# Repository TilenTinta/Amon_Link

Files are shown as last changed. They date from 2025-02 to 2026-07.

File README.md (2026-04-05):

# Amon Link

USB-powered RF bridge between **Amon Ground Control** (PC) and the **Amon Lander** drone, built around the WCH **CH32V003F4P6** MCU with **dual NRF24L01 + RFX2401C** radios for robust range. 

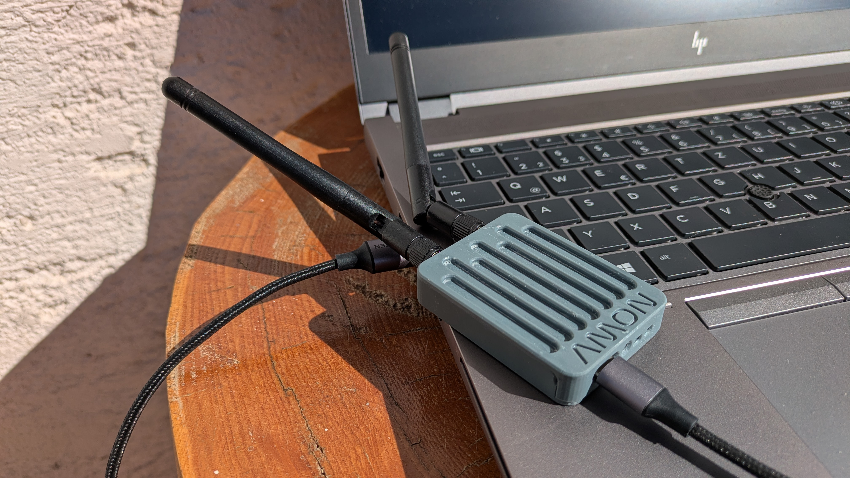
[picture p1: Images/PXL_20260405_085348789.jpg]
Amon Link
  

> Part of the Amon Lander project:
>
> - **Amon Lander** — overall vehicle, frame, test/control SW, and data  
>   https://github.com/TilenTinta/Amon_Lander
> - **Amon Board** — flight controller hardware & firmware  
>   https://github.com/TilenTinta/Amon_Board
> - **Amon Ground Control** — desktop GCS for telemetry & control  
>   https://github.com/TilenTinta/Amon_GroundControl_Software

---

## Table of Contents

- [Overview](#overview)
- [Features](#features)
  - [Hardware](#hardware)
  - [Software & Compatibility](#software--compatibility)
  - [Diagnostics & Controls](#diagnostics--controls)
- [Quick Start](#quick-start)
- [Flashing Firmware](#flashing-firmware)
- [Debugging](#debugging)
  - [LED Status Codes](#led-status-codes)
  - [Button Usage](#button-usage)
- [Repository Structure](#repository-structure)
- [Roadmap](#roadmap)
- [Status & Disclaimer](#status--disclaimer)
- [License](#license)
- [Acknowledgments](#acknowledgments)

---

## Overview

**Amon Link** is a compact, low-power **RF communication bridge** that connects a PC-based Ground Control application to the Amon Lander over 2.4 GHz radios. It prioritizes reliability by pairing **two NRF24L01 modules** with the **RFX2401C PA/LNA** front-end for extended range and improved link quality. The board is powered from **USB Type‑C** and integrates a **3.3 V LDO**. 

---

## Features

### Hardware

- **MCU:** WCH **CH32V003F4P6**. 
- **Power:** USB‑powered with onboard **3.3 V LDO**. 
- **Connector:** **USB Type‑C**. 
- **RF Link:** Dual **NRF24L01** radios with **RFX2401C (PA+LNA)** for long range and better SNR. 
- **Indicators/Controls:** Status LED and button for reconnect/SW update. 

### Software & Compatibility

- **Firmware:** C, developed in **MounRiver Studio IDE**. 
- **USB–UART:** **CH340G** bridge (install drivers if needed). 
- **Platforms:** Works with **Windows, Linux, and macOS** Ground Control apps. 
- **Updates:** **Custom bootloader** supports USB firmware updates. 

### Diagnostics & Controls

- **Status LED** for connection state. 
- **Button** to trigger manual reconnect and entering bootloader mode. 

---

## Quick Start

1. **Connect** the Amon Link board to your PC using **USB‑C**.   
2. **Install drivers** if required for **CH340G**.   
3. **Place antennas** for the two NRF24L01 radios to ensure clear line‑of‑sight where possible.   
4. **Launch** the Amon Ground Control application and select the appropriate COM port.

---

## Flashing Firmware

- Open the project in **MounRiver Studio IDE**, compile, and **upload** to the **CH32V003F4P6** MCU. 

> The board also includes a **custom bootloader** for **USB firmware updates** which is supported by the desktop software. 

### Bootloader
Firmware for device also includes bootloader option. To flash that:
- First flash bootloader (folder: **Bootloader**),
- after that you can flash main **hex** file over USB and desktop app (folder: **Firmware**)

If bootloader is not used you **MUST** modify the code in folder **Firmware**. In file `Link.ld` change code on the top of the file to:

```c
/* Full flash 16KB */
__app_size = 16K;

MEMORY
{
  /* Application region - 16KB */  
	FLASH (rx) : ORIGIN = 0x00000000, LENGTH = __app_size 

  /* RAM - untouched 2KB */  
	RAM (xrw)  : ORIGIN = 0x20000000, LENGTH = 2K
}

SECTIONS
{
  .init :
  {
    ...
```
Once the bootloader is flashed, you can put your device in firmware update mode by holding the **Reconnect** button while plugging in the USB cable or by triggering it via software. When the blue and red LEDs are lights up, you're in firmware update mode!

The firmware can be updated using a graphical application. The application is built with a Python backend and an Electron front end. You can select and import either a hex or a binary file. Once imported, the CRC32 checksum is calculated for the file.

This checksum is used during device connection. When the device connects, a handshake process exchanges several pieces of data, one of which is the CRC32 value of the firmware currently installed on the device. If this CRC matches the one from the new file, you are notified before proceeding with the update. After a successful update, the new CRC32 value is written to the device for future reference.

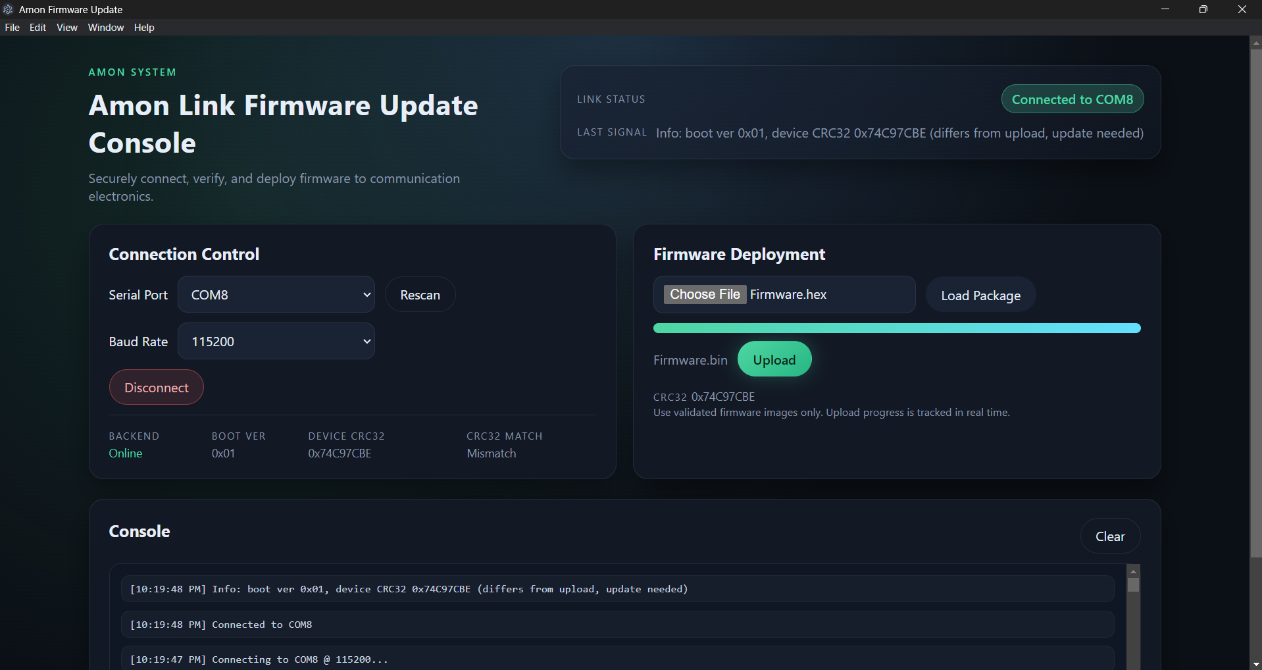
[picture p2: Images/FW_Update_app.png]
Amon Link fw app
  

---

## Debugging

### LED Status Codes  

| LED Pattern (App) | Meaning |
|---|---|
| Constant blinking **red** | Device initialization failed |
| Solid **blue** | Device initialized |
| Blinking **red** | Received packet |

| LED Pattern (Boot) | Meaning |
|---|---|
| Solid **blue** and **red** | Waiting on USB data |

### Button Usage  

Press the **button** to trigger a manual **reconnect** attempt or befor powring up device to enter bootloader mode.

## Range testing
The plan for this device is not to reach over 1 km of range, but only a few meters are enough for now. To test this, I did a simple test. I connected the device to my laptop and established a connection from the **Ground control app** to **Amon Link** and from that to **Amon Lander**. After receiving telemetry data, I started moving away from the drone. This test was done with line of sight between the drone and link device.

Range test  

Because of field limitations, the test was not done until telemetry cut-off. The test will be repeated in the future to really get the limitation of radio range.

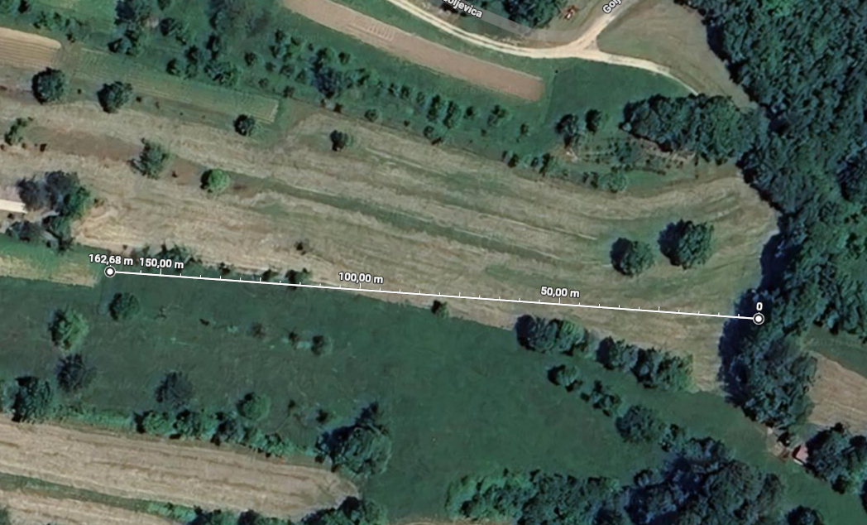
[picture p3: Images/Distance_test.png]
Range test
  

---

## Status & Disclaimer

**In active development.** The hardware and firmware are usable, but changes are ongoing; expect rough edges as features evolve.

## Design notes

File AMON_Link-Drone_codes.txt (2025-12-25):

++++++++++++ Drone state machine ++++++++++++

#define STATUS_STARTUP		0
#define STATUS_IDLE_NC		1 // not connected
#define STATUS_IDLE_CN		2 // connected
#define STATUS_ERROR		3
#define STATUS_ARM			4
#define STATUS_FLY			5
#define STATUS_FLY_OVER		6

#define RF_STATUS_CN		1
#define RF_STATUS_NC		0

++++++++++++ Link state machine ++++++++++++

#define NO_RADIO            1           // Number of radios (1 or 2)

#define CONN_STATUS_OK      1           // Flag that indicates the connection status - connected
#define CONN_STATUS_NOK     0           // Flag that indicates the connection status - disconnected

#define STATE_INIT          0           // State machine value: boot-up (blue light)
#define STATE_CONN_START    1           // State machine value: try to connect (reconnect triggers the same state)
#define STATE_CONN_OK       2           // State machine value: successfully connected (green light on)
#define STATE_CONN_FAIL     3           // State machine value: connect failed (red light blinking, do nothing)

++++++++++++ Communication packets - codes ++++++++++++
Codes used for communicatin between drone, link and PC
Payload bytes

MSB -> LSB
/* Byte 0: Address and command */
// [8-4: address]
0000 - Reserved / null
0001 - PC
0010 - Link (0011 is still link no. 2)
0100 - Drone (all higher numbers can be other drones)

// [4-0: code of the command]
0000 - Reserved / null
0001 - (Link/Drone) Check connection / status report (ping)
0010 - (Link/Drone) Error report - it depands on address
0100 - (Link) Pair status (link to drone)
0101 - (Link) Start pairing (if not allready paired)
0110 - (Link) Current parameters
0111 - (Link) Change parameters on link
1000 - (Drone) Current parameters
1001 - (Drone) Change parameters on drone
1010 - (Drone) Change status on drone
1011 - (Drone) Drone commands (calibrate, save to SD...)
1100 - (Drone) Real time data - telemetry

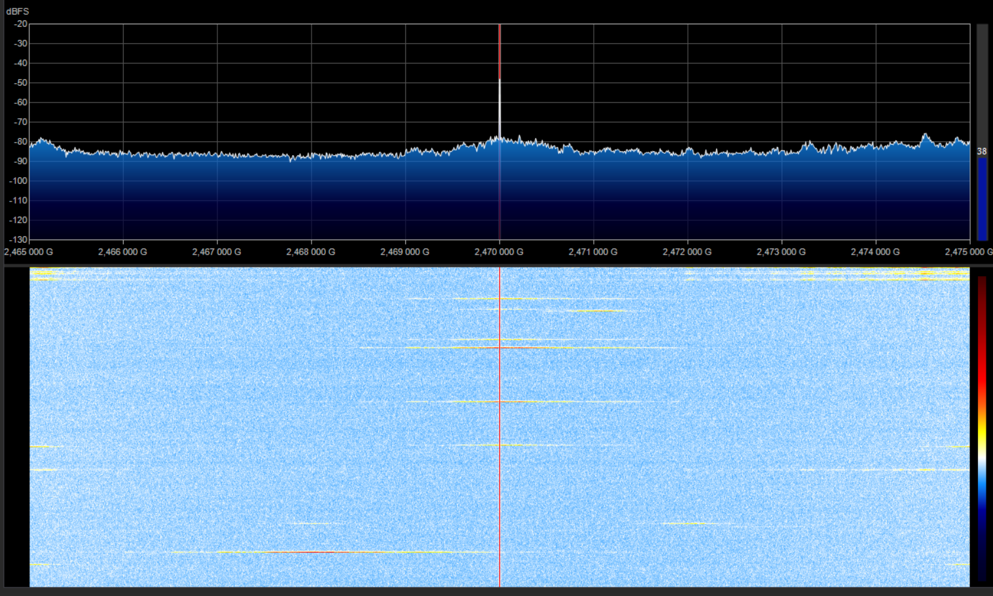
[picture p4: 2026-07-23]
Images/RF_link_2.47GHz_TX.png

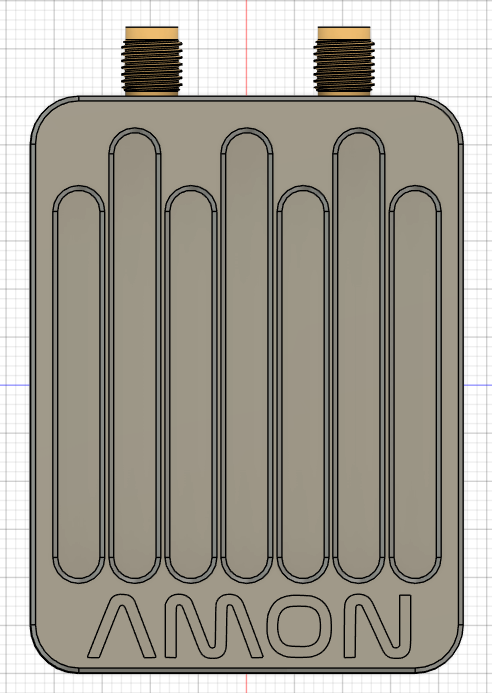
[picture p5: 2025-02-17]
Images/Link3.PNG

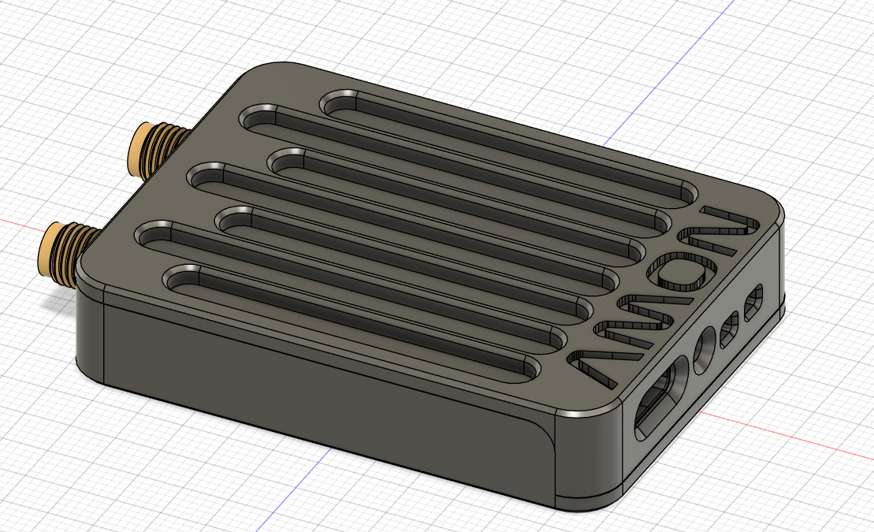
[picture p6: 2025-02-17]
Images/Link1.PNG

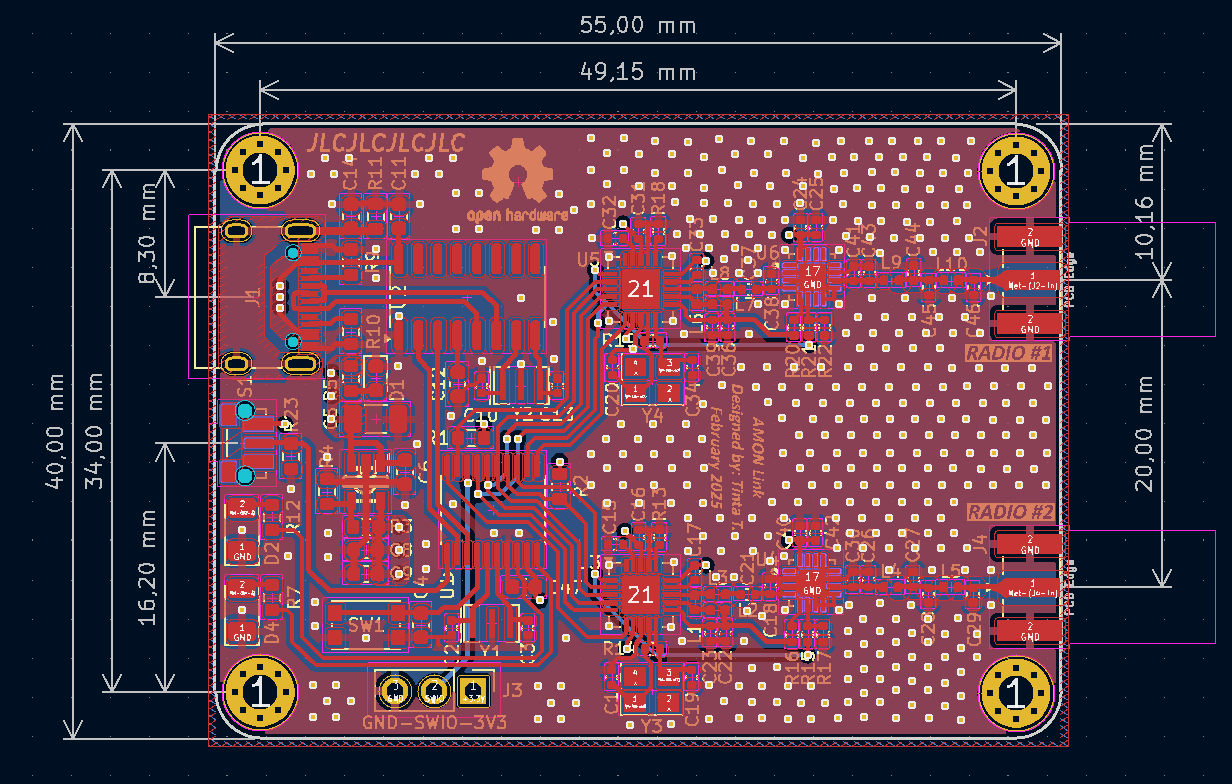
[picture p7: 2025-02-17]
Images/Link_PCB2.PNG

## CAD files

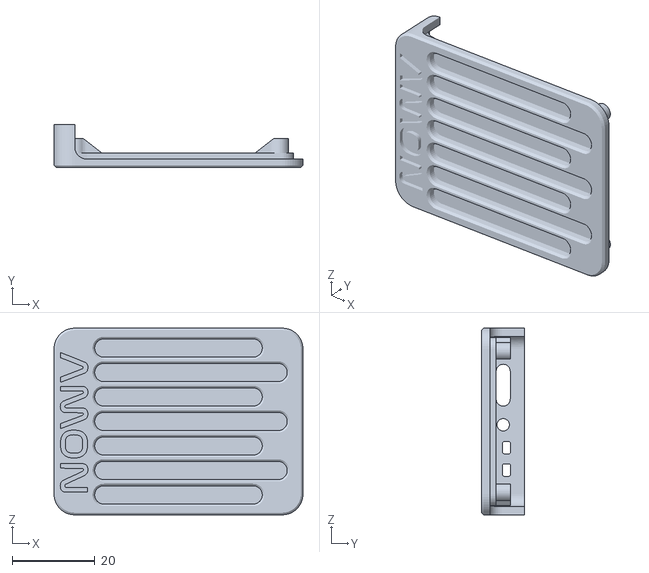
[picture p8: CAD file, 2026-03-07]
Case/Case_top v28.stl
60.0 x 10.3 x 45.0

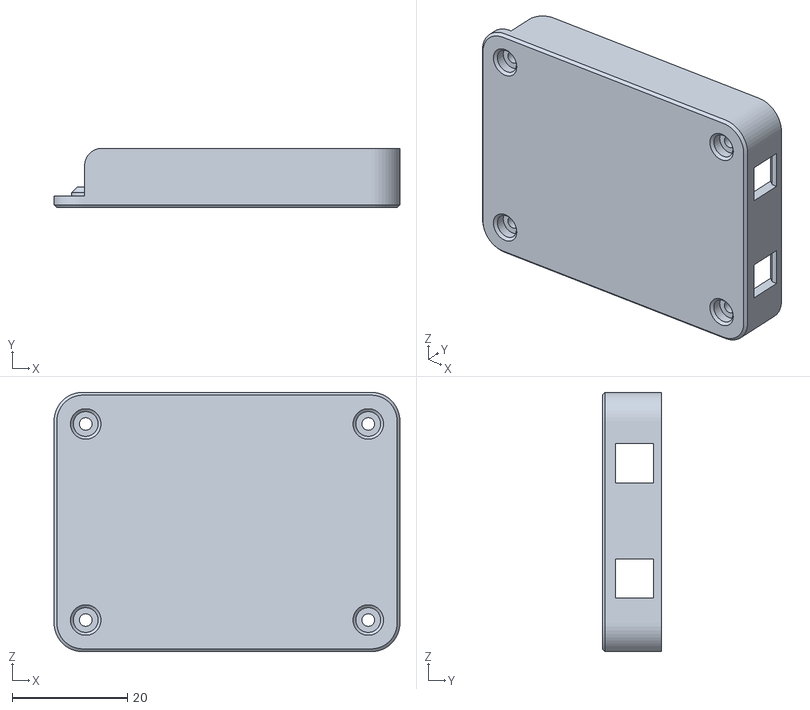
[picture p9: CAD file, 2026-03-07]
Case/Case_base v23.stl
60.0 x 10.3 x 45.0

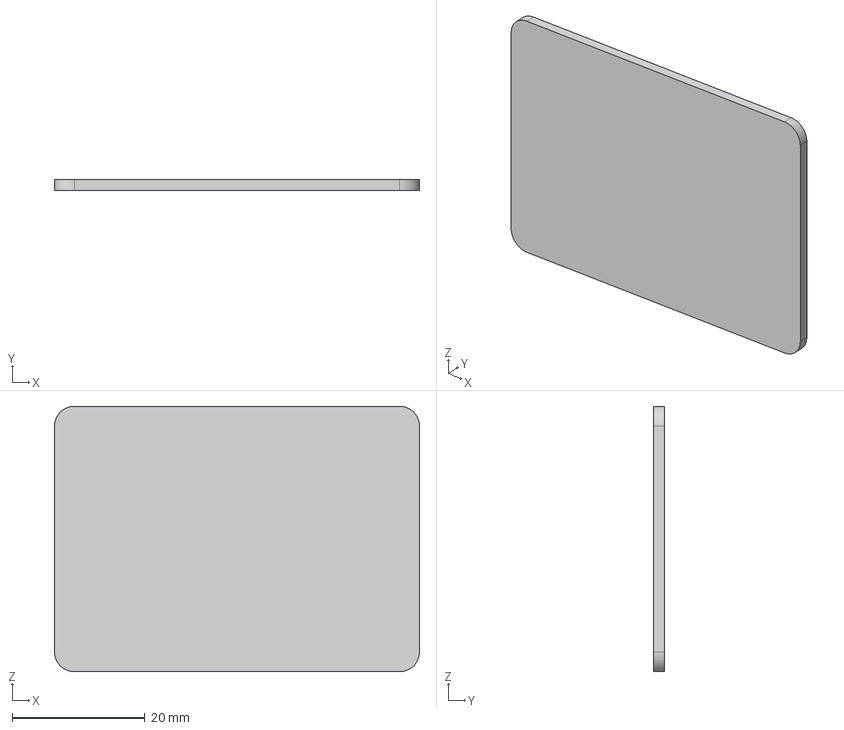
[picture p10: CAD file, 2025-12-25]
Case/PCB_Dummy v3.step
55.0 x 1.60 x 40.0 mm

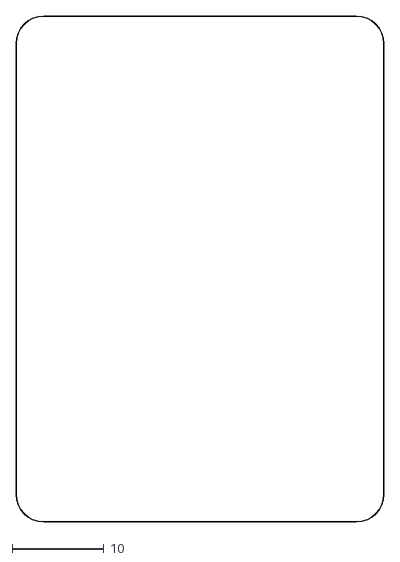
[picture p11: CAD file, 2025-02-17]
Case/PCB_Dummy_v3_1759989030.dxf
40.0 x 55.0

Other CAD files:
Case/Case_base v22.step
Case/Case_top v27.step
Case/Case_base v20.step
Case/Case_base v15.step
Case/Case_top v22.step

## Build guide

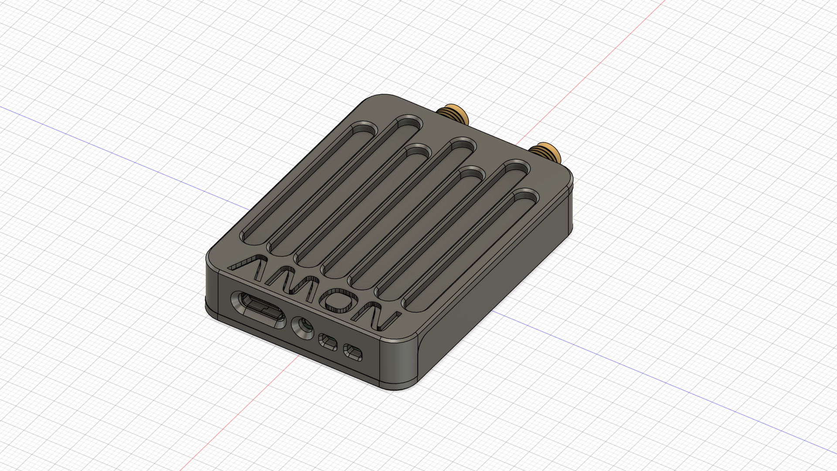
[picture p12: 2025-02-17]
Images/Assembly v5.png

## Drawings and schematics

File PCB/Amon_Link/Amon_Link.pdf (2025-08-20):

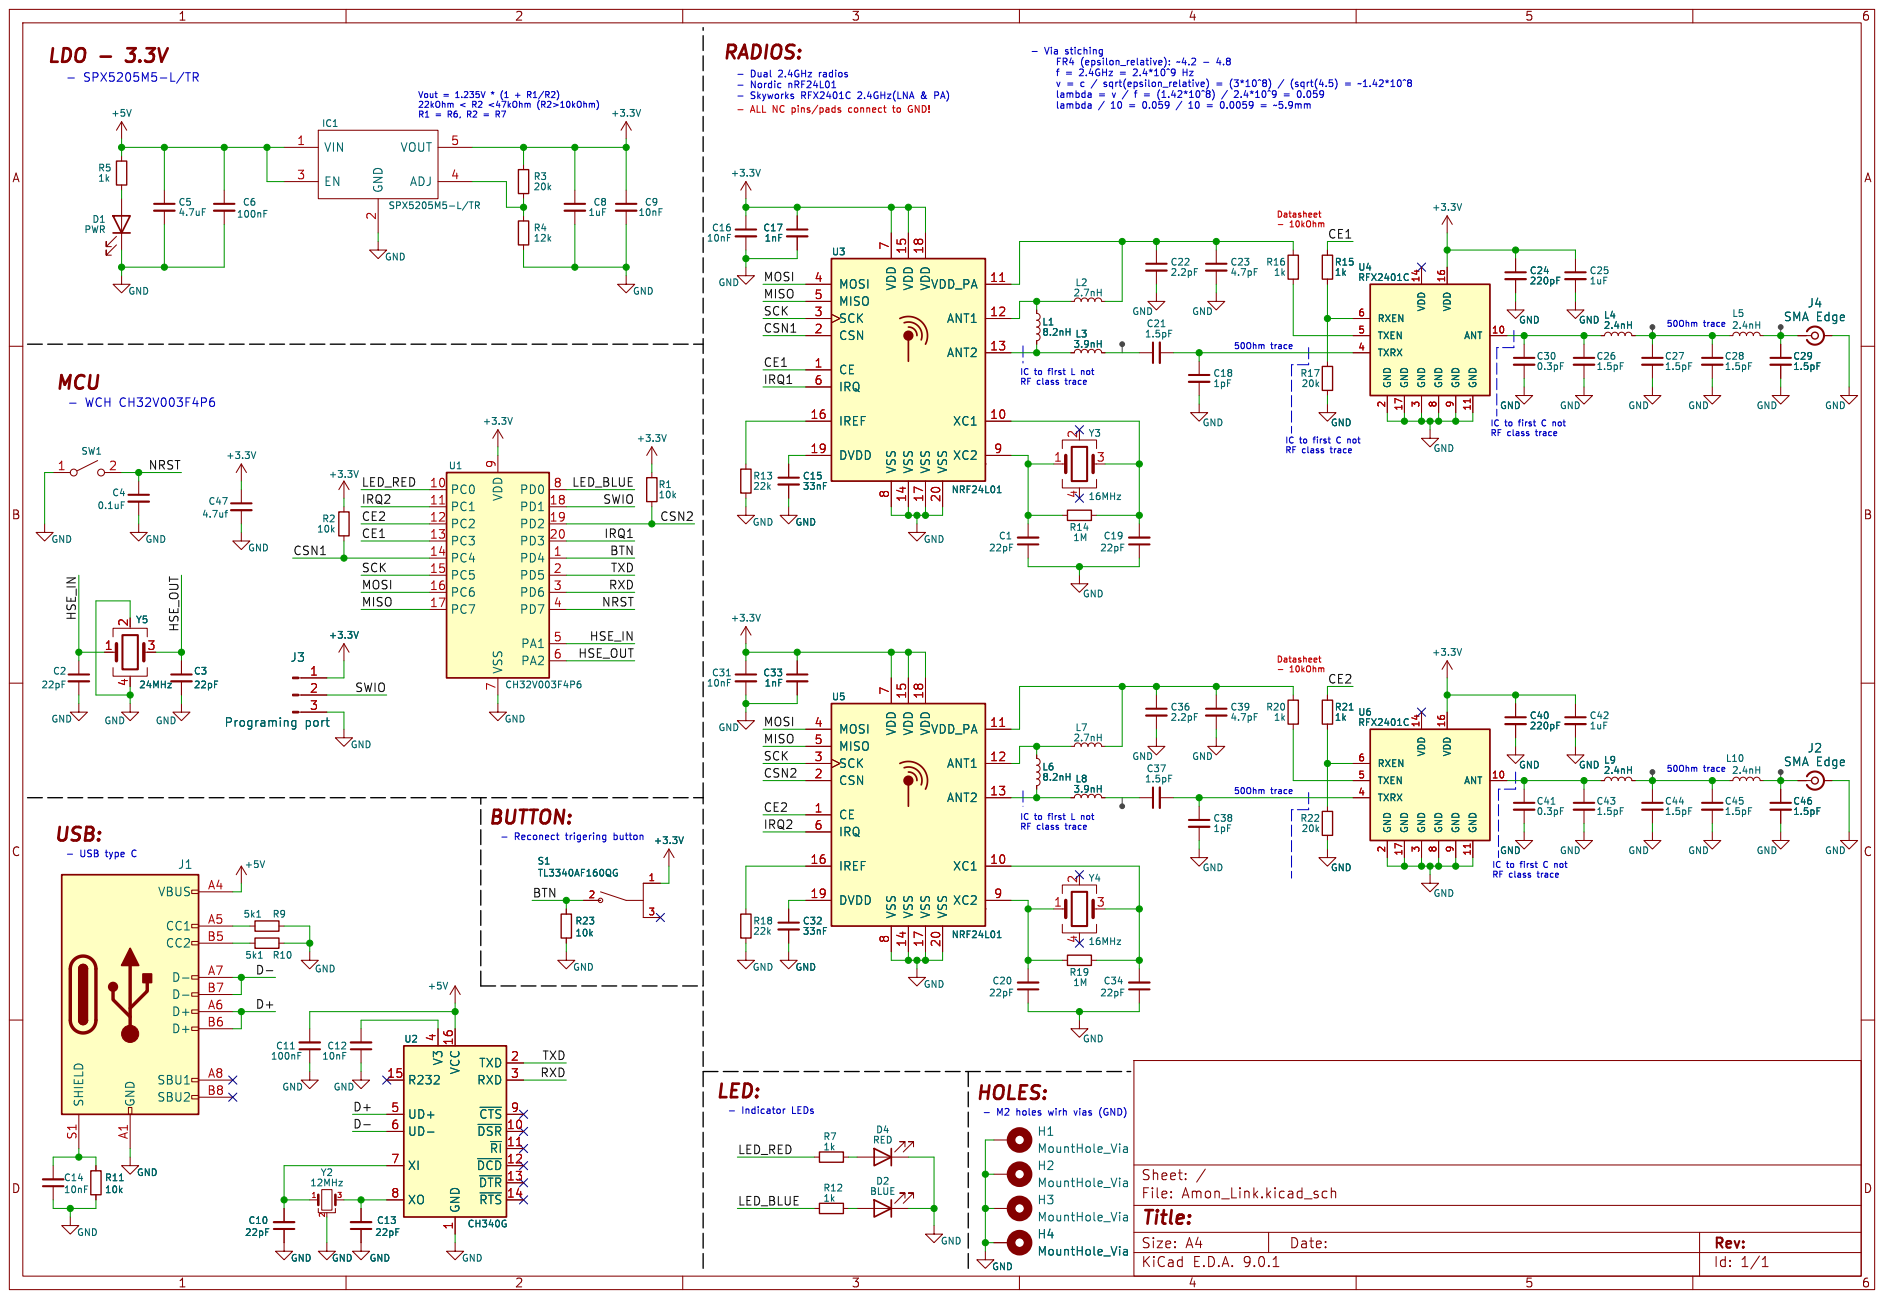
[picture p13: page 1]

8 VDD 15 VSS 14 VDD 18 VSS 17 VSS 20 VDD_PA 11 ANT1 12 ANT2 13 XC1 10 XC2 9 U3 NRF24L01

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

IC to first C not RF class trace Datasheet - 10kOhm

IC to first L not RF class trace

IC to first C not RF class trace

8 VDD 15 VSS 14 VDD 18 VSS 17 VSS 20 VDD_PA 11 ANT1 12 ANT2 13 XC1 10 XC2 9 U5 NRF24L01 1

9 GND 11 ANT 10 GND GNDGND GND

IC to first L not RF class trace LED:

1 TXD 2 RXD 3 ~{CTS}9 ~{DSR} 10 ~{RI} 11 ~{DCD} 12 ~{DTR} 13 ~{RTS} 14 U2 CH340G

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

- M2 holes wirh vias (GND) HOLES:

Id: 1/1 Title: File: Amon_Link.kicad_sch Sheet: /

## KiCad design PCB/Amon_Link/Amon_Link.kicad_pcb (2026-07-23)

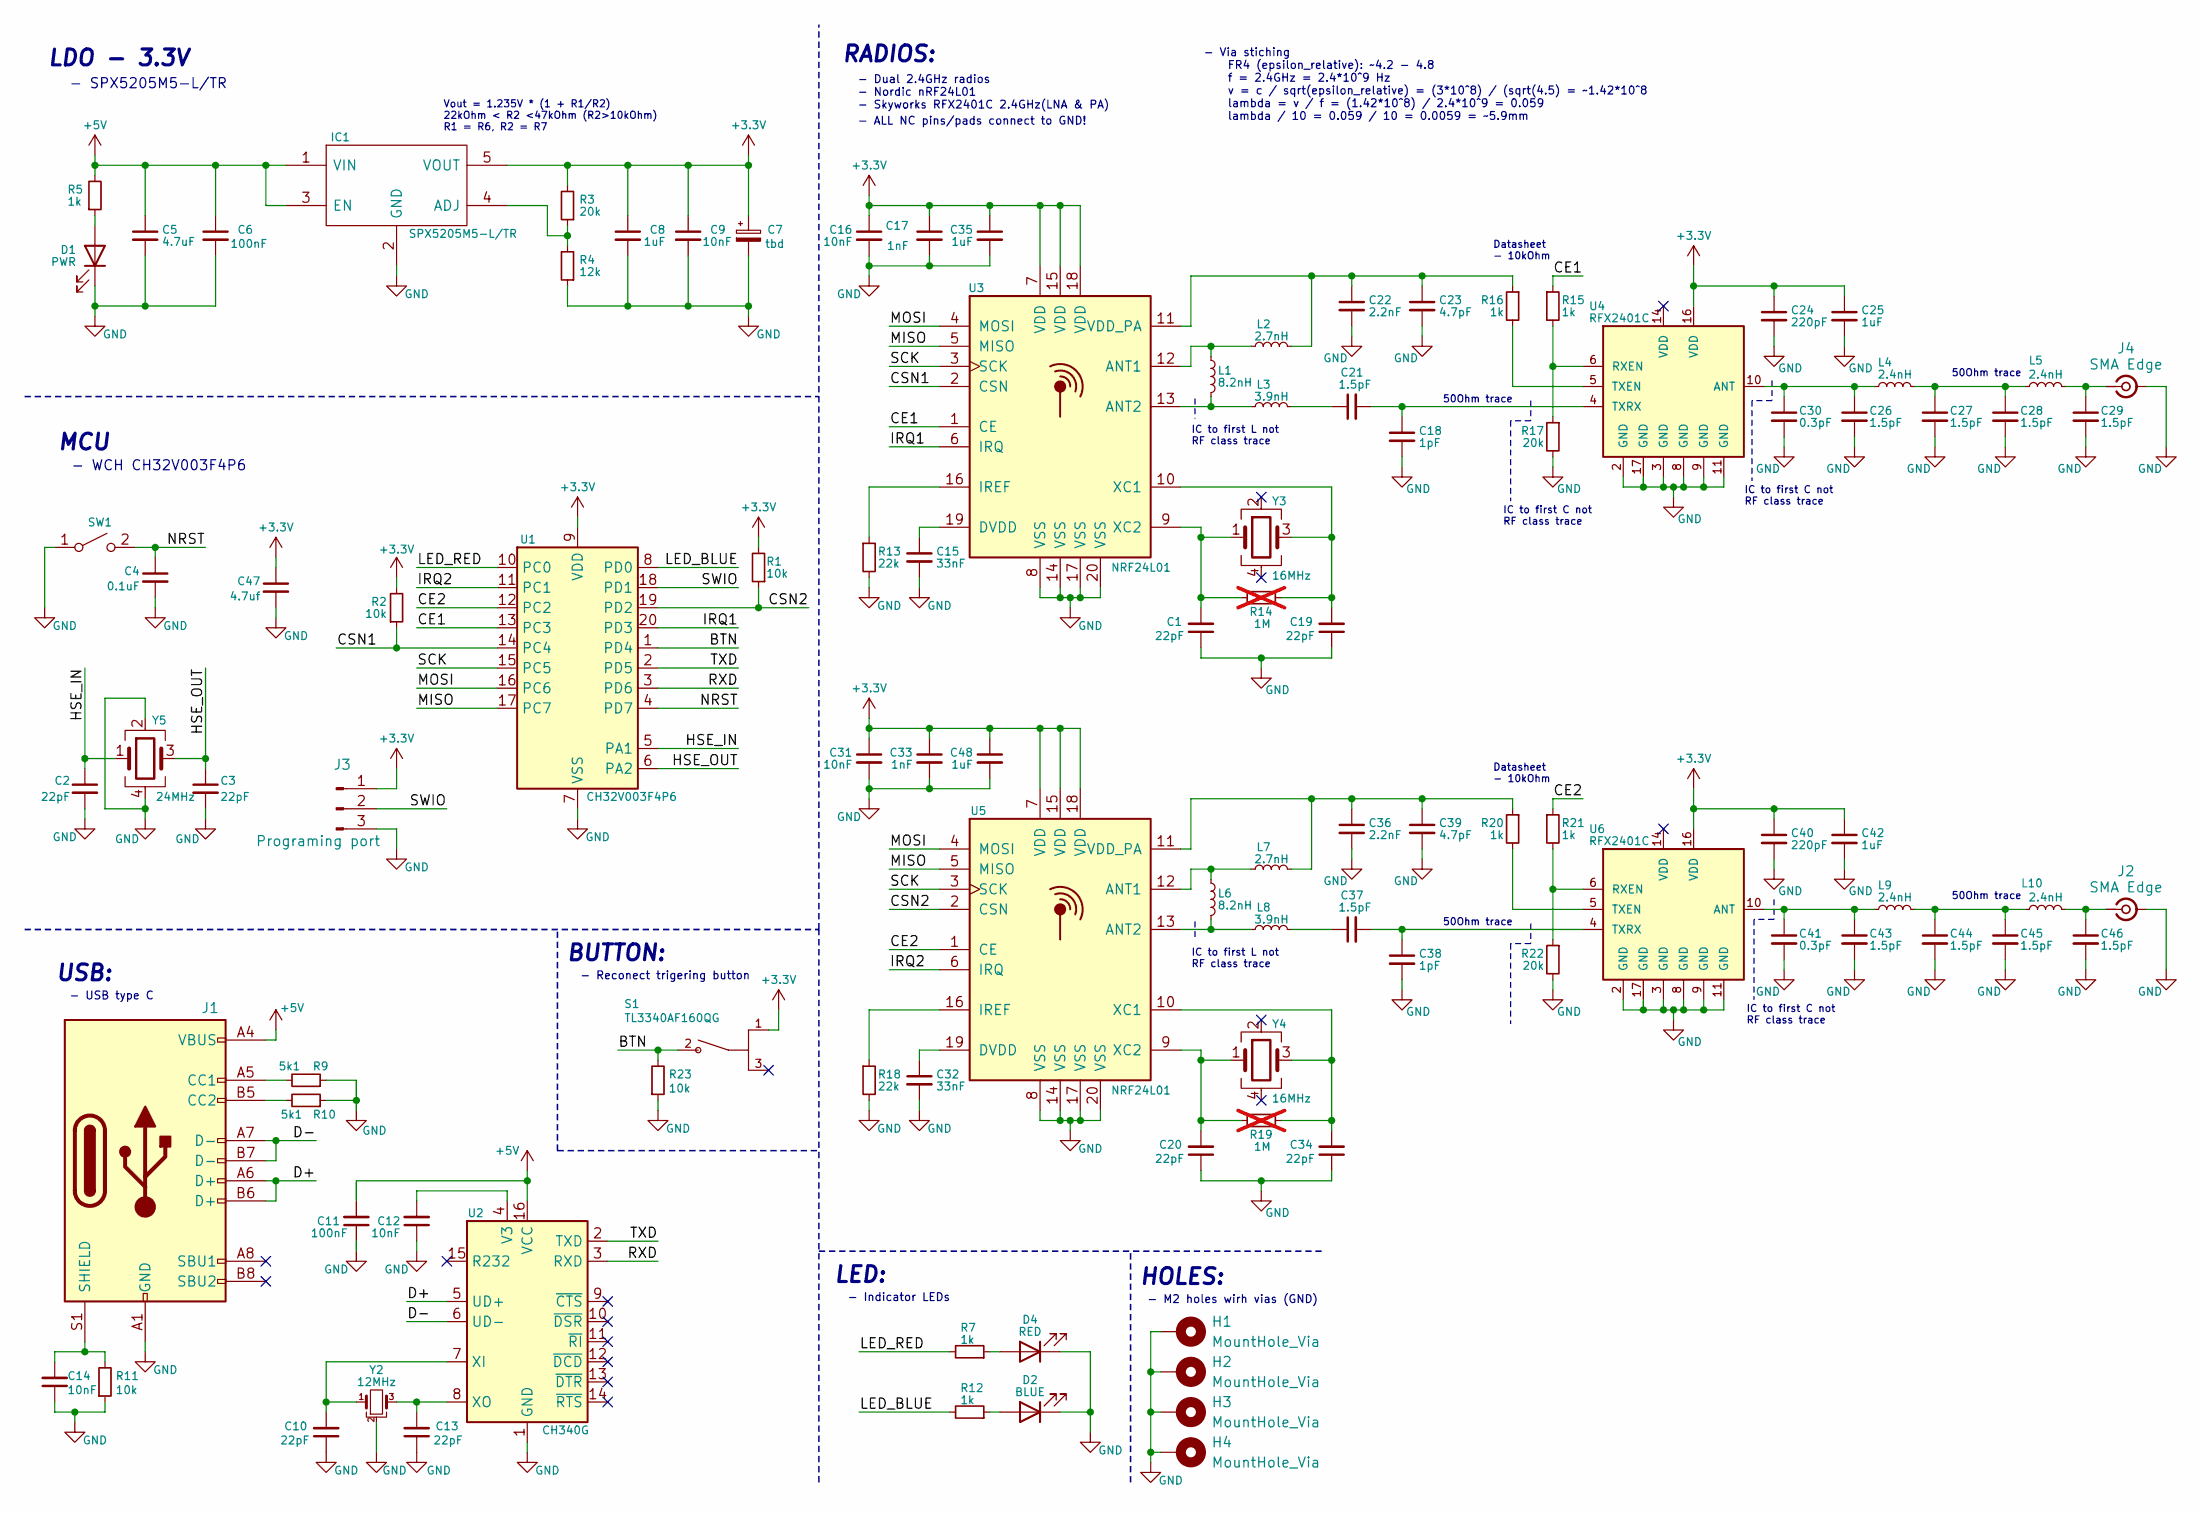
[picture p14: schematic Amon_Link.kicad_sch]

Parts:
C1, C2, C3, C10, C13, C19, C20, C34: 22pF; C_0402_1005Metric
C4: 0.1uF; C_0603_1608Metric
C5: 4.7uF; C_1206_3216Metric
C6, C11: 100nF; C_0603_1608Metric
C7: tbd; CP_EIA-3528-12_Kemet-T
C8: 1uF; C_0603_1608Metric
C9, C12, C14: 10nF; C_0603_1608Metric
C15, C32: 33nF; C_0402_1005Metric
C16, C31: 10nF; C_0402_1005Metric
C17, C33: 1nF; C_0402_1005Metric
C18, C38: 1pF; C_0402_1005Metric
C21, C26, C27, C28, C29, C37, C43, C44, C45, C46: 1.5pF; C_0402_1005Metric
C22, C36: 2.2nF; C_0402_1005Metric
C23, C39: 4.7pF; C_0402_1005Metric
C24, C40: 220pF; C_0402_1005Metric
C25, C35, C42, C48: 1uF; C_0402_1005Metric
C30, C41: 0.3pF; C_0402_1005Metric
C47: 4.7uf; C_0603_1608Metric
D1: PWR; LED_0603_1608Metric
D2: BLUE; LED_1206_3216Metric
D4: RED; LED_1206_3216Metric
H1, H2, H3, H4: MountHole_Via; MountingHole_2.2mm_M2_Pad_Via
IC1: SPX5205M5-L/TR; SOT95P280X145-5N; Manufacturer_Part_Number SPX5205M5-L-3-3/TR; Mouser Part Number 701-SPX5205M5-L-33TR
J1: USB_C_Receptacle_USB2.0; USB_C_Receptacle_XKB_U262-16XN-4BVC11
J2, J4: SMA Edge; SMA_Samtec_SMA-J-P-X-ST-EM1_EdgeMount
J3: Programing port; PinHeader_1x03_P2.54mm_Vertical
L1, L6: 8.2nH; L_0402_1005Metric
L2, L7: 2.7nH; L_0402_1005Metric
L3, L8: 3.9nH; L_0402_1005Metric
L4, L5, L9, L10: 2.4nH; L_0402_1005Metric
R1, R2, R11, R23: 10k; R_0603_1608Metric
R3: 20k; R_0603_1608Metric
R4: 12k; R_0603_1608Metric
R5, R7, R12: 1k; R_0603_1608Metric
R9, R10: 5k1; R_0603_1608Metric
R13, R18: 22k; R_0402_1005Metric
R14, R19: 1M; R_0402_1005Metric; not fitted
R15, R16, R20, R21: 1k; R_0402_1005Metric
R17, R22: 20k; R_0402_1005Metric
S1: TL3340AF160QG; SW_TL3340AF160QG
SW1: SW_SPST; SW_Push_1P1T_NO_CK_KMR2
U1: CH32V003F4P6; TSSOP-20_4.4x6.5mm_P0.65mm
U2: CH340G; SOIC-16_3.9x9.9mm_P1.27mm
U3, U5: NRF24L01; QFN-20-1EP_4x4mm_P0.5mm_EP2.5x2.5mm
U4, U6: RFX2401C; QFN50P300X300X60-17N
Y2: 12MHz; Resonator_SMD_Murata_CSTxExxV-3Pin_3.0x1.1mm
Y3, Y4: 16MHz; Crystal_SMD_3225-4Pin_3.2x2.5mm
Y5: 24MHz; Crystal_SMD_3225-4Pin_3.2x2.5mm

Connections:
+3.3V: C7.1, C8.1, C9.1, C16.1, C17.1, C24.1, C25.1, C31.1, C33.1, C35.1, C40.1, C42.1, C47.1, C48.1, IC1.5 (VOUT), J3.1, R1.2, R2.2, R3.2, S1.1, U1.9 (VDD), U3.7 (VDD), U3.15 (VDD), U3.18 (VDD), U4.16 (VDD), U5.7 (VDD), U5.15 (VDD), U5.18 (VDD), U6.16 (VDD)
+5V: C5.1, C6.1, C11.2, IC1.1 (VIN), IC1.3 (EN), J1.A4 (VBUS), J1.A9 (VBUS), J1.B4 (VBUS), J1.B9 (VBUS), R5.2, U2.16 (VCC)
/BTN: R23.2, S1.2, U1.1 (PD4)
/CE1: R15.1, U1.13 (PC3), U3.1 (CE)
/CE2: R21.1, U1.12 (PC2), U5.1 (CE)
/CSN1: R2.1, U1.14 (PC4), U3.2 (CSN)
/CSN2: R1.1, U1.19 (PD2), U5.2 (CSN)
/D+: J1.A6 (D+), J1.B6 (D+), U2.5 (UD+)
/D-: J1.A7 (D-), J1.B7 (D-), U2.6 (UD-)
/HSE_IN: C2.1, U1.5 (PA1), Y5.1
/HSE_OUT: C3.1, U1.6 (PA2), Y5.3
/IRQ1: U1.20 (PD3), U3.6 (IRQ)
/IRQ2: U1.11 (PC1), U5.6 (IRQ)
/LED_BLUE: R12.2, U1.8 (PD0)
/LED_RED: R7.2, U1.10 (PC0)
/MISO: U1.17 (PC7), U3.5 (MISO), U5.5 (MISO)
/MOSI: U1.16 (PC6), U3.4 (MOSI), U5.4 (MOSI)
/NRST: C4.1, SW1.2 (B), U1.4 (PD7)
/RXD: U1.3 (PD6), U2.3 (RXD)
/SCK: U1.15 (PC5), U3.3 (SCK), U5.3 (SCK)
/SWIO: J3.2, U1.18 (PD1)
/TXD: U1.2 (PD5), U2.2 (TXD)
GND: C1.1, C2.2, C3.2, C4.2, C5.2, C6.2, C7.2, C8.2, C9.2, C10.1, C11.1, C12.1, C13.1, C14.1, C15.2, C16.2, C17.2, C18.2, C19.1, C20.1, C22.2, C23.2, C24.2, C25.2, C26.2, C27.2, C28.2, C29.2, C30.2, C31.2, C32.2, C33.2, C34.1, C35.2, C36.2, C38.2, C39.2, C40.2, C41.2, C42.2, C43.2, C44.2, C45.2, C46.2, C47.2, C48.2, D1.1 (K), D2.1 (K), D4.1 (K), H1.1, H1.MP, H2.1, H2.MP, H3.1, H3.MP, H4.1, H4.MP, IC1.2 (GND), J1.A1 (GND), J1.A12 (GND), J1.B1 (GND), J1.B12 (GND), J2.2 (Ext), J3.3, J4.2 (Ext), R4.1, R9.1, R10.1, R11.1, R13.2, R17.2, R18.2, R22.2, R23.1, SW1.1 (A), U1.7 (VSS), U2.1 (GND), U3.8 (VSS), U3.14 (VSS), U3.17 (VSS), U3.20 (VSS), U4.2 (GND), U4.3 (GND), U4.8 (GND), U4.9 (GND), U4.11 (GND), U4.17 (GND), U5.8 (VSS), U5.14 (VSS), U5.17 (VSS), U5.20 (VSS), U6.2 (GND), U6.3 (GND), U6.8 (GND), U6.9 (GND), U6.11 (GND), U6.17 (GND), Y2.2, Y5.2, Y5.4
unnamed: C21.1, L3.2
unnamed: C27.1, C28.1, L4.2, L5.1
unnamed: C37.1, L8.2
unnamed: C44.1, C45.1, L9.2, L10.1
unnamed: D1.2 (A), R5.1
unnamed: D2.2 (A), R12.1
unnamed: D4.2 (A), R7.1
unnamed: IC1.4 (ADJ), R3.1, R4.2
unnamed: J1.A5 (CC1), R9.2
unnamed: J1.B5 (CC2), R10.2
unnamed: C14.2, J1.S1 (SHIELD), R11.2
unnamed: C46.1, J2.1 (In), L10.2
unnamed: C29.1, J4.1 (In), L5.2
unnamed: C12.2, U2.4 (V3)
unnamed: C10.2, U2.7 (XI), Y2.1
unnamed: C13.2, U2.8 (XO), Y2.3
unnamed: L1.1, L2.1, U3.12 (ANT1)
unnamed: L1.2, L3.1, U3.13 (ANT2)
unnamed: C15.1, U3.19 (DVDD)
unnamed: R13.1, U3.16 (IREF)
unnamed: C22.1, C23.1, L2.2, R16.1, U3.11 (VDD_PA)
unnamed: C19.2, R14.2, U3.10 (XC1), Y3.3
unnamed: C1.2, R14.1, U3.9 (XC2), Y3.1
unnamed: C26.1, C30.1, L4.1, U4.10 (ANT)
unnamed: R15.2, R17.1, U4.6 (RXEN)
unnamed: R16.2, U4.5 (TXEN)
unnamed: C18.1, C21.2, U4.4 (TXRX)
unnamed: L6.1, L7.1, U5.12 (ANT1)
unnamed: L6.2, L8.1, U5.13 (ANT2)
unnamed: C32.1, U5.19 (DVDD)
unnamed: R18.1, U5.16 (IREF)
unnamed: C36.1, C39.1, L7.2, R20.1, U5.11 (VDD_PA)
unnamed: C34.2, R19.2, U5.10 (XC1), Y4.3
unnamed: C20.2, R19.1, U5.9 (XC2), Y4.1
unnamed: C41.1, C43.1, L9.1, U6.10 (ANT)
unnamed: R21.2, R22.1, U6.6 (RXEN)
unnamed: R20.2, U6.5 (TXEN)
unnamed: C37.2, C38.1, U6.4 (TXRX)

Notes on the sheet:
IC to first C not RF class trace
Vout = 1.235V * (1 + R1/R2) 22kOhm < R2 <47kOhm (R2>10kOhm) R1 = R6, R2 = R7
BUTTON:
50Ohm trace
RADIOS:
- Reconect trigering button
- Via stiching FR4 (epsilon_relative): ~4.2 - 4.8 f = 2.4GHz = 2.4*10^9 Hz v = c / sqrt(epsilon_relative) = (3*10^8) / (sqrt(4.5) = ~1.42*10^8 lambda = v / f = (1.42*10^8) / 2.4*10^9 = 0.059 lambda / 10 = 0.059 / 10 = 0.0059 = ~5.9mm
IC to first L not RF class trace
- ALL NC pins/pads connect to GND!
- Dual 2.4GHz radios - Nordic nRF24L01 - Skyworks RFX2401C 2.4GHz(LNA & PA)
Datasheet - 10kOhm
LDO - 3.3V
- M2 holes wirh vias (GND)
USB:
- USB type C
HOLES:
- Indicator LEDs
- WCH CH32V003F4P6
MCU
LED:
- SPX5205M5-L/TR

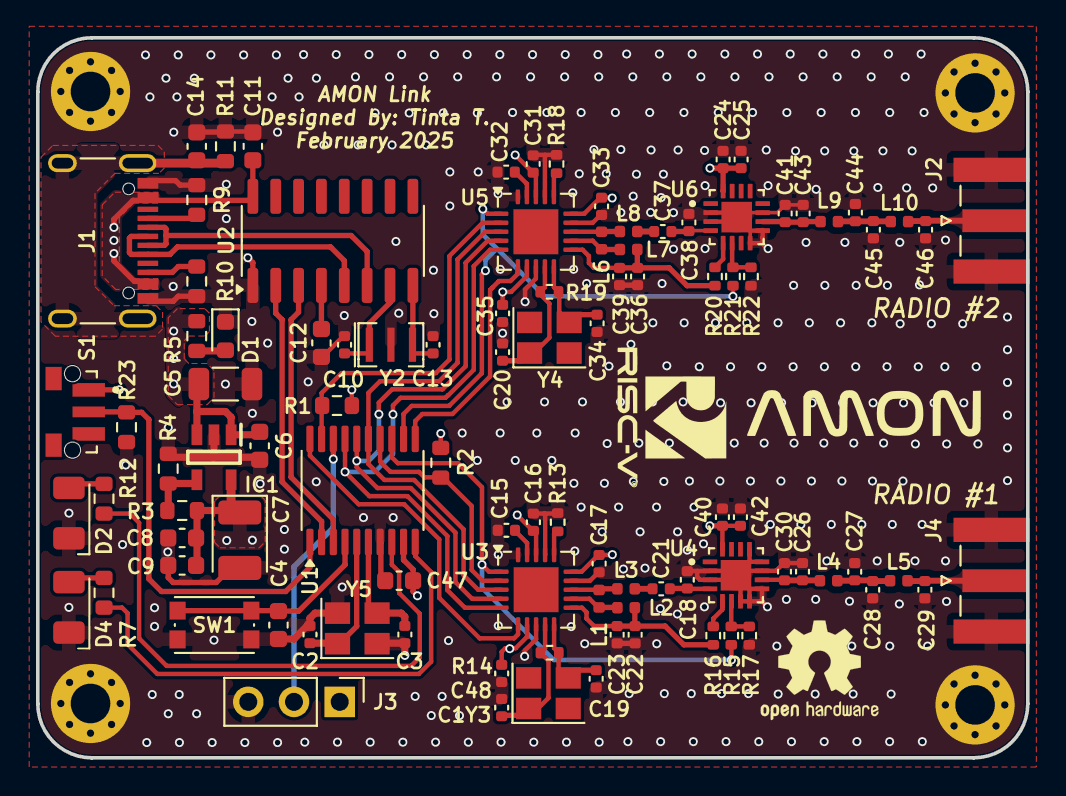
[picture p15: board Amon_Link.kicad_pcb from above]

Board: 4 copper layers, 55.0 x 40.0 mm, 103 parts (0 on the bottom side), 61 nets.

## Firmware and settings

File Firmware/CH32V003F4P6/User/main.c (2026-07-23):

/*****************************************************************
 * File Name          : main.c
 * Author             : Tinta T.
 * Version            : V1.0.0
 * Date               : 2025/02/11
 * Description        : Main file of Amon Link
*****************************************************************/

/* Includes */
#include "debug.h"
#include "main.h"


/*###########################################################################################################################################################*/
/* Interrupts defines */
void USART1_IRQHandler(void) __attribute__((interrupt("WCH-Interrupt-fast")));
void EXTI7_0_IRQHandler(void) __attribute__((interrupt("WCH-Interrupt-fast")));
void TIM2_IRQHandler(void) __attribute__((interrupt("WCH-Interrupt-fast")));



/*###########################################################################################################################################################*/
/* Functions */
void USART1_Init(void);
void SPI1_Init(void);
void LinkPinout_Init(void);
void TIM_INT_Init(void);
void UartSendBuffer(uint8_t* buffer, uint16_t length);
void UART_buffer_clear(void);
void USART_DMA_TX_Config();
void Start_DMA_USART_TX(uint8_t len);
void SPI_DMA_RX_Config();
void Start_DMA_SPI_RX(void);

// Bootloader related functions
void flash_read_boot_flag(s_meta_data *data);
void flash_read_crc32(s_meta_data *data);
void system_reset_trigger(void);
void flash_save_metadata(s_meta_data *data);


/*###########################################################################################################################################################*/
/* Global define */
s_device device;                                            // Device variables struct
s_buffers buffers;                                          // Device buffers
s_packets data_packets;                                     // Packets struct
s_meta_data metadata;                                       // Metadata used for bootloader
s_nRF24L01 radio1;                                          // Radio variables 1
s_nRF24L01 radio2;                                          // Radio variables 2
SPI_HandleTypeDef hspi1;                                    // SPI handle


// Radio 1 configurations (application specific)
static const s_nrf_config radio_tx_normal_cfg = {
    .channel = 70,
    .addr_width = AW_5BYTE,
#ifdef RADIO_HW_ACK
    .auto_ack = 1,
#else
    .auto_ack = 0,
#endif
    .dynamic_payload = 1,
    .retries = 15, // 8
    .retry_delay = ARD_3500us, // ARD_1000us
    .datarate = NRF_DATARATE_1MBPS,
    .power = NRF_POWER_0DBM,   
};

static const s_nrf_config radio_tx_stream_cfg = {
    .channel = 70,
    .addr_width = AW_5BYTE,
    .auto_ack = 0,
    .dynamic_payload = 1,
    .retries = 15, // 8
    .retry_delay = ARD_3500us, // ARD_1000us
    .datarate = NRF_DATARATE_1MBPS,
    .power = NRF_POWER_0DBM,   
};

static const s_pipe_addr radio_tx_addr = {
    //.tx_addr = { 0xE7, 0xE7, 0xE7, 0xE7, 0xE7 }
    .tx_addr = { 0xD4, 0xB2, 0xAA, 0x78, 0x50 }
};

// Radio 1 configurations (application specific)
static const s_nrf_config radio_rx_normal_cfg = {
    .channel = 100, //100
    .addr_width = AW_5BYTE,
#ifdef RADIO_HW_ACK
    .auto_ack = 1,
#else
    .auto_ack = 0,
#endif
    .dynamic_payload = 1,
    .retries = 0,
    .retry_delay = 0,
    .datarate = NRF_DATARATE_1MBPS,
    .power = NRF_POWER_MINUS_6DBM,
};

static const s_nrf_config radio_rx_stream_cfg = {
    .channel = 100, //100
    .addr_width = AW_5BYTE,
    .auto_ack = 0,
    .dynamic_payload = 1,
    .retries = 0,
    .retry_delay = 0,
    .datarate = NRF_DATARATE_1MBPS,
    .power = NRF_POWER_MINUS_6DBM,
};

static const s_pipe_addr radio_rx_addr = {
    //.pipe0_rx_addr = { 0xE7, 0xE7, 0xE7, 0xE7, 0xEE } //0xE8
    .pipe0_rx_addr = { 0xC2, 0xA1, 0x55, 0x12, 0x01 } 
};



/* ########################################### --- MAIN --- ########################################### */

int main(void)
{
    // Device init //
    NVIC_PriorityGroupConfig(NVIC_PriorityGroup_1);         // Init NVIC
    SystemCoreClockUpdate();                                // Init all the clocks
    Delay_Init();                                           // Enable delay
    LinkPinout_Init();                                      // Init the pinout
    TIM_INT_Init();                                         // Init the timer
    USART1_Init();                                          // Init USART
    //USART_Printf_Init(115200);                              // Enable USART
    USART_DMA_TX_Config();                                  // Configure DMA channel 4 - USART TX (UDP style telemetry data)
    SPI1_Init();                                            // Init SPI
    //SPI_DMA_RX_Config();                                    // Configure DMA channel 2 - SPI RX (UDP style telemetry data)


    // Device start //
    if (device.init_done == 0)
    {
        // Device is alive 
        //GPIO_WriteBit(GPIOC, LED_RED, Bit_SET);             
        GPIO_WriteBit(GPIOD, LED_BLUE, Bit_SET); 

        GPIO_WriteBit(GPIOC, NRF_CE1, Bit_RESET);
        GPIO_WriteBit(GPIOC, NRF_CE2, Bit_RESET); 
        GPIO_WriteBit(GPIOC, NRF_CS1, Bit_SET);
        GPIO_WriteBit(GPIOD, NRF_CS2, Bit_SET);         

        device.device_id = DBGMCU_GetCHIPID();              // Get unic device ID
        flash_read_boot_flag(&metadata);                    // Read boot flag value
        flash_read_crc32(&metadata);                        // Read current firmware CRC32
        if (metadata.flags == 1)                            // Bootloop protection
        {
            metadata.flags = 0;
            flash_save_metadata(&metadata);                 
        } 
        device.version = SW_VER;                            // Version of software
        device.state = STATE_INIT;                          // Start device state
        device.conn_status = CONN_STATUS_NOK;               // Connection status
        device.conn_type = STATE_DATA_TRANSMIT;             // Communication type - clasic

        radio1.op_modes = NRF_MODE_PWR_ON_RST;              // set default radio state
        radio2.op_modes = NRF_MODE_PWR_ON_RST;              // set default radio state
        device.flag_lost_connection = 0;
        device.flag_data_stream = 0;
        radio1.irq_on_pipe = 0xFF;
        radio2.irq_on_pipe = 0xFF;

        device.init_done = 1;                               // Block init 

        __enable_irq();
    }


    while(1)
    {
        /*/////////////////////// USB TRANSCODING HANDLING ///////////////////////*/
        if (buffers.flag_new_uart_rx_data == 1) 
        {
            buffers.flag_new_uart_rx_data = 0;

            uint8_t ret = UART_decode(buffers.buffer_UART, &data_packets, &buffers.flag_new_rf_tx_data);
            memset(buffers.buffer_UART, 0, sizeof(buffers.buffer_UART));

            // Based on return values trigger events
            switch (ret) 
            {
                case TRANSCODE_BOOT_PKT:
                    system_reset_trigger();             // Bootloader reboot detection
                    break;
                
                case TRANSCODE_BROADCAST:
                    device.state = STATE_RUNNING;       // Trigger new reconections
                    device.flag_data_stream = 0;
                    break;
                
                case TRANSCODE_VER_ERR:                 // Wrong version of packet
                    break;
                
                case TRANSCODE_DEST_ERR:                // Wrong destination address
                    break;

                case TRANSCODE_CRC_ERR:                 // Corupted frame / CRC
                    break;
                    
                case TRANSCODE_DEST_RF:                 // Packet for RF transmit
                    device.flag_data_stream = 0;
                    break;

                case TRANSCODE_DEST_LINK:               // Packet for link device
                    device.flag_data_stream = 0;
                    device.flag_link_command_rx = 1;    // Report link command 
                    break;

                default:                                // Default state
                    break;
            }
        }


        /*/////////////////////// RF TRANSCODING HANDLING ///////////////////////*/
        if (buffers.flag_new_rf_rx_data == 1) 
        {
            buffers.flag_new_rf_rx_data = 0;

            // TODO: Decode
            uint8_t ret = RF_decode(radio2.buffers.RX_FIFO, &data_packets, &buffers.flag_new_uart_tx_data); //, &device.flag_data_stream

            // Based on return values trigger events
            switch (ret) 
            {
                case TRANSCODE_BOOT_PKT:                // Wrong destination address
                    break;
                
                case TRANSCODE_BROADCAST:               // Unavailable command
                    break;
                
                case TRANSCODE_VER_ERR:                 // Wrong version of packet
                    break;
                
                case TRANSCODE_DEST_ERR:                // Wrong destination address
                    break;

                case TRANSCODE_CRC_ERR:                 // Corupted frame / CRC
                    break;
                    
                case TRANSCODE_DEST_PC:                 // Packet for PC SW
                    device.flag_data_stream = 1;
                    break;
                
                case TRANSCODE_DEST_LINK:               // Packet for Link device
                    break;
            }

            if (device.flag_data_stream == 1)
            {
                radio2.config = &radio_rx_stream_cfg;
                NRF24_init(&radio2);
                //GPIO_WriteBit(GPIOC, LED_RED, Bit_SET);
            }
        }


        /*/////////////////////// RADIO IRQ HANDLING ///////////////////////*/
        if (radio1.irq_flag == 1)
        {   
            // TX
            NRF24_HandleIRQ(&radio1);
            radio1.buffers.pipe_data = radio1.irq_on_pipe;
            radio1.irq_flag = 0;
            radio1.irq_on_pipe = 0xFF;
        }

        if (radio2.irq_flag == 1)
        {
            // RX
            NRF24_HandleIRQ(&radio2);
            radio2.buffers.pipe_data = radio2.irq_on_pipe;
            radio2.irq_flag = 0;
            radio2.irq_on_pipe = 0xFF;
        }
        


        /*/////////////////////// MAIN STATE MACHINE ///////////////////////*/
        switch(device.state)
        {

            // STATE: Initialize all devices on the PCB
            case STATE_INIT:

                // Short pause for devices to fully power on
                Delay_Ms(1000); 
            
                // Base UART data
                char startDevInfo[] = "----- AMON Link -----\r\n";
                UartSendBuffer((uint8_t*)startDevInfo, strlen(startDevInfo)); 

                char idLabel[] = "Device ID: ";
                UartSendBuffer((uint8_t*)idLabel, strlen(idLabel));
                UartSendBuffer((uint8_t*)&device.device_id, sizeof(device.device_id));

                char newline[] = "\r\n";
                UartSendBuffer((uint8_t*)newline, strlen(newline));


                // Radios initialization and setup
                NRF24_pin_config(&radio1, SPI1, GPIOC, NRF_CS1, GPIOC, NRF_CE1);        // Map pins for radio 1
                NRF24_pin_config(&radio2, SPI1, GPIOD, NRF_CS2, GPIOC, NRF_CE2);        // Map pins for radio 2

                Delay_Ms(100);

                uint8_t status = 0;
                NRF24_ReadStatus(&radio1, &status);
                if (status == 0x00 || status == 0xFF)
                {
                    radio1.radioErr = NRF_ERR_BOOT;
                }
                else
                {
                    // Radio answered
                    NRF24_WriteRegister(&radio1, STATUS, RX_DR | TX_DS | MAX_RT, NULL);
                    radio1.radioErr = NRF_ERR_NONE;
                    radio1.op_modes = NRF_MODE_PWR_DOWN;
                }

                Delay_Ms(10); // Safe delay for checking radio status

                if (NRF24_ReadStatus(&radio2, &status) == 0) 
                {
                    if (status == 0x00 || status == 0xFF)
                    {
                        radio2.radioErr = NRF_ERR_BOOT;
                    }
                    else
                    {
                        // Radio answered
                        NRF24_WriteRegister(&radio2, STATUS, RX_DR | TX_DS | MAX_RT, NULL);
                        radio2.radioErr = NRF_ERR_NONE;
                        radio2.op_modes = NRF_MODE_PWR_DOWN;
                    }
                }

                Delay_Ms(10);

                // Set radio configurations and init
                if (radio1.radioErr != 1)
                {
                    radio1.role     = NRF_ROLE_PTX;
                    radio1.config   = &radio_tx_normal_cfg;
                    radio1.address  = &radio_tx_addr;
                    radio1.id       = NRF_ID_1;

                    NRF24_SetTXAddress(&radio1, radio1.address->tx_addr);
                    NRF24_init(&radio1);
                    NRF24_ReadStatus(&radio1, &status);
				    if (status != 0x0E) radio1.radioErr = NRF_ERR_BOOT;
                }
                
                Delay_Ms(10);

                if (radio2.radioErr != 1)
                {
                    radio2.role     = NRF_ROLE_PRX;
                    radio2.config   = &radio_rx_normal_cfg;
                    radio2.address  = &radio_rx_addr;
                    radio2.id       = NRF_ID_2;

                    NRF24_SetRXAddress(&radio2, 0, radio2.address->pipe0_rx_addr);
                    NRF24_init(&radio2);
                    NRF24_ReadStatus(&radio2, &status);
				    if (status != 0x0E) radio2.radioErr = NRF_ERR_BOOT;;
                    
                }

                //NRF24_ReadStatus(&radio1, &status); // Clear all irqs

                // End of initialization
                GPIO_WriteBit(GPIOC, LED_RED, Bit_RESET);
                GPIO_WriteBit(GPIOD, LED_BLUE, Bit_RESET);

                // Check radio initialization
                if (radio1.radioErr == NRF_ERR_BOOT || radio2.radioErr == NRF_ERR_BOOT)
                {
                    device.state = STATE_FAIL;          // Trigger init fail
                } 
                else
                {
                    device.state = STATE_RUNNING;       // OK... continue
                    GPIO_WriteBit(GPIOD, LED_BLUE, Bit_SET);
                }
                                                
                break;



            // STATE: Device and drone are connected, data can be send/received
            case STATE_RUNNING:

                // Trigger packet sending by button press
                if (device.flag_btn_rcon == 1)
                {
                    data_packets.rf_packet.version = SW_VER;
                    data_packets.rf_packet.flags = FLAG_DATA;
                    data_packets.rf_packet.src_id = ID_PC;
                    data_packets.rf_packet.dest_id = ID_DRONE;
                    data_packets.rf_packet.opcode = OPT_PAIR_START;
                    data_packets.rf_packet.plen = 0;
                    RF_encode(&data_packets, radio1.buffers.TX_FIFO, &radio1.buffers.tx_lenght);
                    NRF24_Send(&radio1);
                    device.flag_btn_rcon = 0;
                }
                

                // ### Experimental - only option to get signal quality
                /*
                {
                    uint8_t arc = NRF24_GetLinkQuality(&radio1);

                    if (arc <= 1)       radio1.strength = LINK_EXCELLENT;
                    else if (arc <= 4)  radio1.strength = LINK_GOOD;
                    else if (arc <= 8)  radio1.strength = LINK_WEAK;
                    else                radio1.strength = LINK_BAD;
                }
                */


                // Select what type of communication will be used (Drone to PC)
                switch (device.conn_type) 
                {
                    
                    // Clasic data transmition - IRQ, parameters to/from drone
                    case STATE_DATA_TRANSMIT:
                        {
                            // ### New data available to send -> send
                            // # RF #
                            if (buffers.flag_new_rf_tx_data)
                            {
                                RF_encode(&data_packets, radio1.buffers.TX_FIFO, &radio1.buffers.tx_lenght);
                                
                                // If data is send (critical) -> ACK required
                                if (device.flag_data_stream == 1)
                                {
                                    radio2.config = &radio_rx_normal_cfg;
                                    NRF24_init(&radio2);
                                    GPIO_WriteBit(GPIOC, LED_RED, Bit_RESET);
                                }

                                NRF24_Send(&radio1);
                                buffers.flag_new_rf_tx_data = 0;
                            }

                            // # UART #
                            if (buffers.flag_new_uart_tx_data)
                            {
                                buffers.flag_new_uart_tx_data = 0;
                                UART_encode(&data_packets, buffers.buffer_UART);
                                UartSendBuffer(buffers.buffer_UART, (data_packets.uart_packet.len + 2)); //sizeof(buffers.buffer_UART)
                                //memcpy(buffers.buffer_UART, buffers.bufferDMA_RF_UART, sizeof(buffers.buffer_UART));
                                //Start_DMA_USART_TX((data_packets.uart_packet.len + 2));

                                if (device.flag_data_stream)
                                {
                                    uint8_t val = GPIO_ReadOutputDataBit(GPIOC, LED_RED);
                                    GPIO_WriteBit(GPIOC, LED_RED, (int)(!val));  
                                } 
                                else
                                {
                                    GPIO_WriteBit(GPIOC, LED_RED, Bit_RESET); 
                                }
                            }

                        }


                        // ### Transmited data
                        if (radio1.buffers.flag_tx_done) 
                        {
                            // success
                            device.pct_tx_cnt++;
                            radio1.buffers.flag_tx_done = 0;
                        }

                        if (radio1.buffers.flag_max_rxs_reached) 
                        {
                            device.pct_fail_cnt++;
                            radio1.buffers.flag_max_rxs_reached = 0;

                            // Report failed transmit - problem in PC client
                            // UART_report_err_tx(&data_packets);
                            // UART_encode(&data_packets, buffers.buffer_UART);
                            // UartSendBuffer(buffers.buffer_UART, sizeof(buffers.buffer_UART));

                            if (device.pct_fail_cnt >= 5)
                            {
                                device.flag_lost_connection = 1;
                                //device.state = STATE_CONN_FAIL;
                            } 
                        }


                        // ### Receive data
                        if (radio2.buffers.flag_new_rx)
                        {
                            NRF24_ReadRXPayload(&radio2);
                            //buffers.flag_new_uart_tx_data = 1;
                            buffers.flag_new_rf_rx_data = 1;
                        }


                        // Decode data for Link device
                        if (device.flag_link_command_rx)
                        {
                            device.flag_link_command_rx = 0;

                            switch (data_packets.uart_packet.opcode) 
                            {
                                case OPT_TELEMETRY_STREAM:

                                    if (data_packets.uart_packet.payload[0] == 1)
                                    {
                                        device.flag_data_stream = 1;
                                        GPIO_WriteBit(GPIOC, LED_RED, Bit_SET);
                                    }
                                    else
                                    {
                                        device.flag_data_stream = 0;
                                        GPIO_WriteBit(GPIOC, LED_RED, Bit_RESET); 
                                    }
                                    break;

                                default:
                                    break;
                            }
                        }
                        
                    break;
                    
                    // High speed data transmition - UDP style
                    case STATE_DATA_STREAM:
                        // TODO: Optimize for dma (disable all timer interrupts, SPI optimization)
                        //Start_DMA_USART_TX(sizeof(buffers.bufferDMA_RF_UART));
                        //UartSendBuffer((uint8_t*)&device.device_id, sizeof(device.device_id));
                        
                    break;

                    // Undefined - go in error
                    default:
                        device.state = STATE_CONN_FAIL;
                    break;
                }       
                break;
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

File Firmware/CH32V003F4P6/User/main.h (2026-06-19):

/*****************************************************************
 * File Name          : main.h
 * Author             : Tinta T.
 * Version            : V1.0.0
 * Date               : 2025/02/11
 * Description        : Main header file of Amon Link
*****************************************************************/

#ifndef USER_MAIN_H_
#define USER_MAIN_H_

/* Includes */
#include <stdio.h>
#include <stdint.h>
#include <string.h>
#include "NRF24L01/NRF24L01.h"              // Library for radios
#include "DataTranscode/data_transcode.h"   // Encoders and decoder for data frafic
#include "device.h"                         // Helper functions for device


/*###########################################################################################################################################################*/
/* Defines */

// Device constants
#define DEVICE_NAME    "AMON Link"      // Name of the device
#define SW_VER              1           // Software version (used in UART packets)
#define SW_DATE        "February 2025"  // Date of software
#define APP_END_ADDRESS     0x08004000  // End address of flash
#define PAGE_SIZE           64          // Page size in bytes
#define APP_METADATA_ADDR   APP_END_ADDRESS - PAGE_SIZE // Address in flash where FW data is stored (flags, CRC32) - 64 Bytes

#define RADIO_NO            2           // Number of radios (1 or 2)
//#define RADIO_HW_ACK				    // Uncomment to enable use of HW ACK function provided by IC (NRF24L01) TODO

#define STATE_INIT          0           // State machine value: boot-up (blue light)
#define STATE_RUNNING       1           // State machine value: device initializet correctly, data trafic is running
#define STATE_CONN_FAIL     2           // State machine value: connect failed (red light blinking, do nothing)
#define STATE_IDLE          3           // State machine value: state where device doesnt do anything
#define STATE_FAIL          4           // State machine value: device initialization fail

#define CONN_STATUS_OK      1           // Flag that indicates the connection status - connected
#define CONN_STATUS_NOK     0           // Flag that indicates the connection status - disconnected

#define STATE_DATA_TRANSMIT 0           // State of communication where only commands and response will be transmited - changed with take off / landing
#define STATE_DATA_STREAM   1           // State of communication where drone will stream telemetry and stuf - changed with take off / landing


// Pinout
#define LED_RED             GPIO_Pin_0  // PC0: Pin of red LED
#define LED_BLUE            GPIO_Pin_0  // PD0: Pin of blue LED
#define BTN_PIN             GPIO_Pin_4  // PD4: Pin of reconnect button

#define USART_RX            GPIO_Pin_6  // PD6: USART RX pin (mistake - pin remaping)
#define USART_TX            GPIO_Pin_5  // PD5: USART TX pin (mistake - pin remaping)

#define NRF_MOSI            GPIO_Pin_6  // PC6: SPI MOSI pin for radios
#define NRF_MISO            GPIO_Pin_7  // PC7: SPI MISO pin for radios
#define NRF_SCK             GPIO_Pin_5  // PC5: SPI SCK pin for radios
#define NRF_CS1             GPIO_Pin_4  // PC4: SPI chip select pin for radio 1
#define NRF_CS2             GPIO_Pin_2  // PD2: SPI chip select pin for radio 2
#define NRF_CE1             GPIO_Pin_3  // PC3: chip enable pin for radio 1
#define NRF_CE2             GPIO_Pin_2  // PC2: chip enable pin for radio 2
#define NRF_IRQ1            GPIO_Pin_3  // PD3: interrupt pin for radio 1
#define NRF_IRQ2            GPIO_Pin_1  // PC1: interrupt pin for radio 2


/*###########################################################################################################################################################*/
/* Structs */

typedef struct{

    uint32_t    device_id;              // MCU ID number (identifying the device)
    uint8_t     version;                // Version of FW (based on protocol)
    uint8_t     init_done;              // Block the initialisation process
    volatile uint8_t     state;         // Main state machine variable
    uint8_t     err_code;               // Error code used for error report

    volatile uint8_t     conn_status;   // Flag that indicates state of connection with drone
    volatile uint8_t     conn_type;     // Type of communication - transmit/stream
    uint16_t    pct_tx_cnt;             // Send packets counter
    uint16_t    pct_rx_cnt;             // Received packets counter
    uint8_t     flag_lost_connection;   // Flag that indicates connection lost (after n of retransmitions)
    uint8_t     flag_btn_rcon;          // Flag for button triggered reconnection
    uint16_t    pct_fail_cnt;           // Counter for failed packets (calculated based on packet number - if next packet num. is not +1 -> pct_fail_cnt++)
    uint8_t     flag_data_stream;       // Flag for data stream mode (radio init change)
    uint8_t     flag_link_command_rx;   // Flag for received command targeted for link device

} s_device;
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

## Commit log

2024-01-10 First commit, case, pcb on purfboardu, FW without SPI
    [Antena_cap v1.step, Antena_cap v1.stl, Case v4.step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]
2025-02-15 AVR to RISC-V
    [Amon_Link.kicad_pcb, Amon_Link.kicad_sch, Antena_cap v1.step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]
2025-02-17 shematic done, layout in progress
    [Amon_Link.kicad_pcb, Amon_Link.kicad_sch, PCB_Dummy v1.step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]
2025-02-17 pcb update and case
    [Amon_Link-B_Cu.gbr, Amon_Link-B_Mask.gbr, Amon_Link-B_Paste.gbr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]
2025-03-09 PCB: added graphics, Firmware: USART IRQ working, pinout set
    [Amon_Link.kicad_pcb, Amon_Link.kicad_sch, Case_base v15.stl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]
2025-08-20 Update
    PCB v0.1 complete, firmware in progress
    [Amon_Link-B_Cu.gbr, Amon_Link-B_Mask.gbr, Amon_Link-B_Paste.gbr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]
2025-08-23 Update
    code update - leds, button, connect states, timers
2025-08-24 Update
    IRQ flags correction, pin remaping for UART, working USB communication, SPI configured, both radios has connection with mcu
    [NRF24L01.c, NRF24L01.h, main.c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]
2025-10-12 update
    usb-uart
2025-10-26 Bootloder
    Basic button bootloader routine with no firmware update implementation
    [Amon_Link.kicad_pcb]
2025-11-23 Update
    Receiving commands with CRC calculaton from PC
    [Case_base v18.step, Case_top v23.step]
2025-12-25 Update
    Terminl app to GUI app (Python + Electron)
    [Case_base v20.stl, Case_base v22.step, Case_base v22.stl]
2025-12-29 Update
    added gui update report, reset option from main application on device
    [dataDecoder.c, main.c, main.h]
2026-01-11 Update
    nRF25L01 driver complete, untested
    [Amon_Link.kicad_sch]
2026-01-14 Update
    nRF25L01 driver complete, tested, data encoding_decoding
2026-01-21 Update
    radio parameter tune
    [Amon_Link.kicad_pcb, Amon_Link.kicad_sch]
2026-01-24 Update
    radio driver send timeout
2026-02-02 Update
    power stability optimization on PCB - added Cs for TX event
    [Amon_Link.kicad_pcb, Amon_Link.kicad_sch]
2026-03-07 Update
    Added flags
    [Case_base v22.stl, Case_base v23.stl, Case_top v27.stl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]
2026-06-14 Bugfix: alowing short ACK messages
    [Amon_Link.kicad_pcb]
2026-07-23 Update: channel setup correction
    [Amon_Link.kicad_pcb]
